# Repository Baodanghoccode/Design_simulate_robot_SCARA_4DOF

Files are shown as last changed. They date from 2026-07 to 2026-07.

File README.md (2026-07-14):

# SCARA 4-DOF Robot: Design, Simulation & Control

A full-cycle robotics project — from dynamic modeling and control design (MATLAB/Simulink), to mechanical design (SolidWorks), to a Python GUI driving a real Arduino-based prototype.

## Demo

- [Simulation & trajectory visualization](https://youtu.be/2t7z2ixyt3Y)
- [Real hardware motor control](https://youtu.be/OuQhNZBY79Q)

## Project Overview

This project covers the complete design cycle of a **4-DOF SCARA (Selective Compliance Assembly Robot Arm)**, made of 3 revolute joints and 1 prismatic (vertical) joint. The goal was to take the robot from a mathematical model all the way to a physical, motor-driven prototype:

- Derive the robot's dynamic equations of motion (mass and Coriolis matrices) from its physical parameters.
- Plan smooth joint trajectories between arbitrary start/end poses.
- Design a **computed-torque (PID) controller** and validate it in Simulink before deploying to hardware.
- Model and manufacture the mechanical structure in SolidWorks.
- Build a Python desktop application that visualizes the robot in 3D and can drive the physical arm over a serial link to Arduino.

## System Architecture

```
Trajectory Planning  →  Dynamic Control (PID)  →  Hardware (Arduino + motors)
   (MATLAB, cubic         (Simulink, mass matrix               ↓
    polynomial)            M(q) & Coriolis C(q,q̇))   Visualization (Python GUI)
```

1. **Trajectory Planning** (`matlab/traj_planning_4dof.m`) generates a smooth cubic-polynomial path for each of the 4 joints between a start and goal configuration.
2. **Dynamic Control** (`matlab/RobotScara.slx`) feeds the desired trajectory into a computed-torque control loop, using the robot's dynamic model (`matrixM.m`, `matrixC.m`) to compute the joint torques needed to track it.
3. **Hardware** — the resulting joint commands are sent over a USB-serial link to an Arduino, which drives the physical motors and reports back real joint positions.
4. **Visualization** — a Python/Tkinter GUI renders the robot in 3D in real time, using the same forward-kinematics engine whether it's driving a pure simulation or the live hardware.

## Hardware Wiring Diagram

<p align="center">
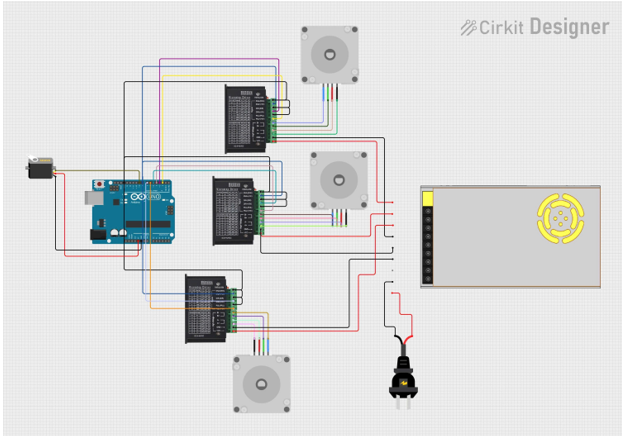
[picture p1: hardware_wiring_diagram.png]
Hardware wiring diagram: Arduino, TB6600 drivers, Nema17 motors, servo and power supply
  
</p>

Arduino Uno as the central controller, driving 3× TB6600 stepper drivers (one per stepper joint) plus a servo for the gripper, powered by a 24V switching power supply.

## Repository Structure

```
├── matlab/
│   ├── Main_Scara4dof.m          # Robot physical parameters (mass, inertia, link length) + PID gains
│   ├── traj_planning_4dof.m      # Cubic-polynomial joint trajectory generator
│   ├── matrixM.m / matrixC.m     # Mass matrix M(q) and Coriolis matrix C(q, q̇)
│   ├── tinhMa.m / tinhb.m        # Computed-torque control terms
│   ├── RobotScara.slx            # Simulink model: dynamics + PID control loop
│   ├── RobotScara.xml / RobotScara_DataFile.m
│   └── Part*.STEP                # Link geometry (STEP)
├── solidworks/                   # Native SolidWorks CAD (5 parts + assembly)
├── scara_fk_trajectory(code ve quy dao).py       # Python GUI: FK + 3D trajectory simulation (no hardware needed)
├── scara_fk_arduino (code giao dien+ketnoiarduino).py  # Python GUI: same visualization + live serial link to Arduino
└── README.md
```

## Technical Highlights

**Trajectory planning** — each of the 4 joints follows a smooth 3rd-order polynomial (zero velocity at start/end):

```
q(t) = q0 + (3/T²)(qf - q0)·t² - (2/T³)(qf - q0)·t³
```

**Dynamic control (computed torque / PID)** — uses the robot's own dynamic model to linearize and decouple the system:

```
τ = M(q)·a + C(q, q̇)·q̇ + G(q)
```

**Hardware loop** — the Arduino script streams computed joint targets over serial, reads back real position data, and renders the live 3D pose in the same GUI used for pure simulation.

## Tech Stack

`MATLAB` · `Simulink` · `SolidWorks` · `Python (Tkinter, Matplotlib, NumPy, PySerial)` · `Arduino`

## Running the Simulator

```bash
pip install numpy matplotlib pyserial
python "scara_fk_trajectory(code ve quy dao).py"              # simulation only
python "scara_fk_arduino (code giao dien+ketnoiarduino).py"   # connects to Arduino
```

## Authors

Nguyễn Tiến Bảo · Nguyễn Việt Bách

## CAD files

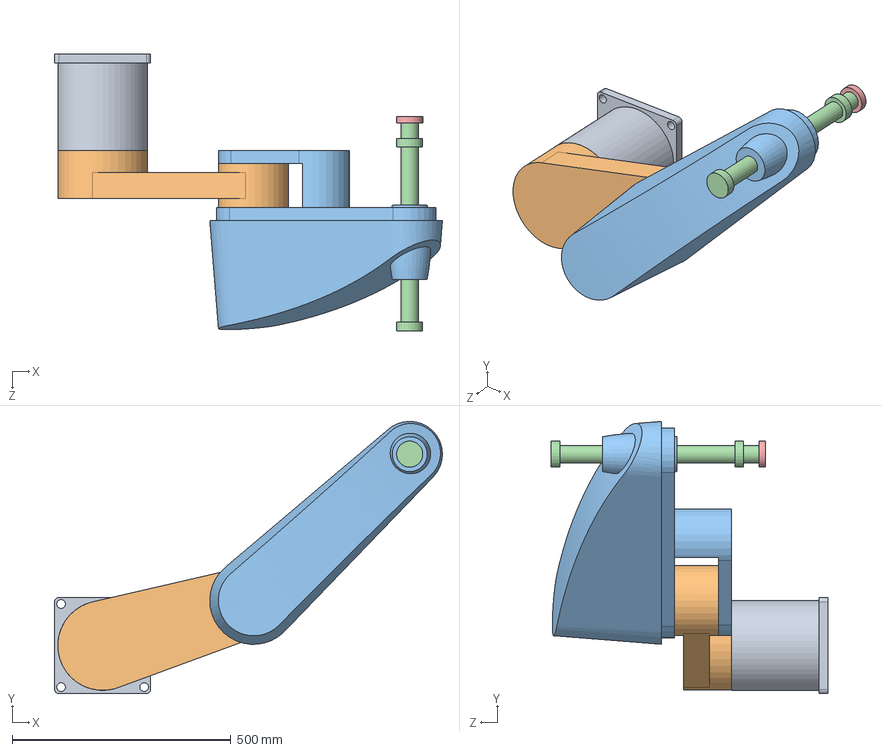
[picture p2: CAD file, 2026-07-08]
solidworks/RobotScara.SLDASM
887.5 x 622.8 x 632.5 mm

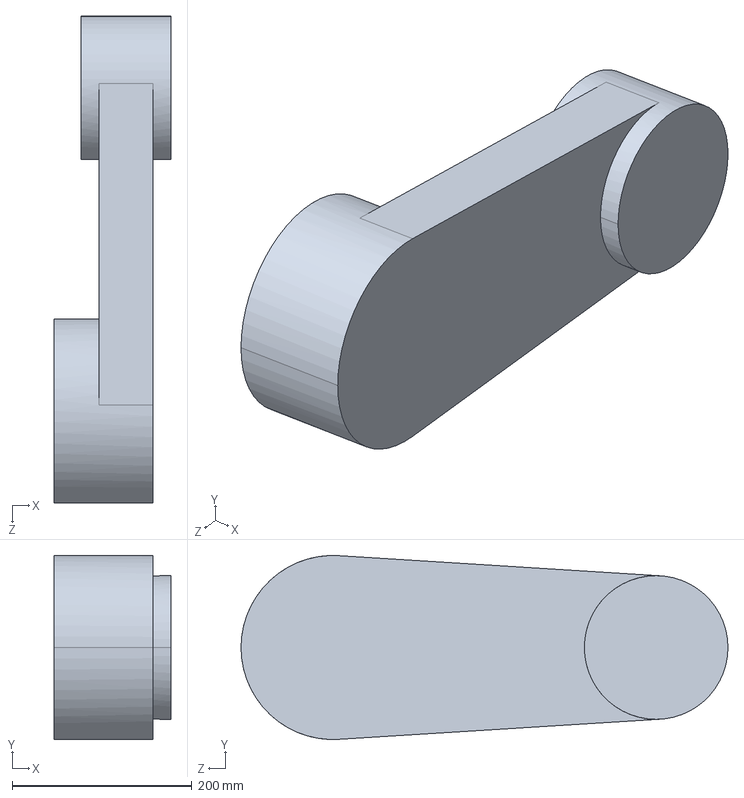
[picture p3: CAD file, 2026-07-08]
matlab/Part2_Default_sldprt.STEP
130.0 x 205.0 x 542.5 mm

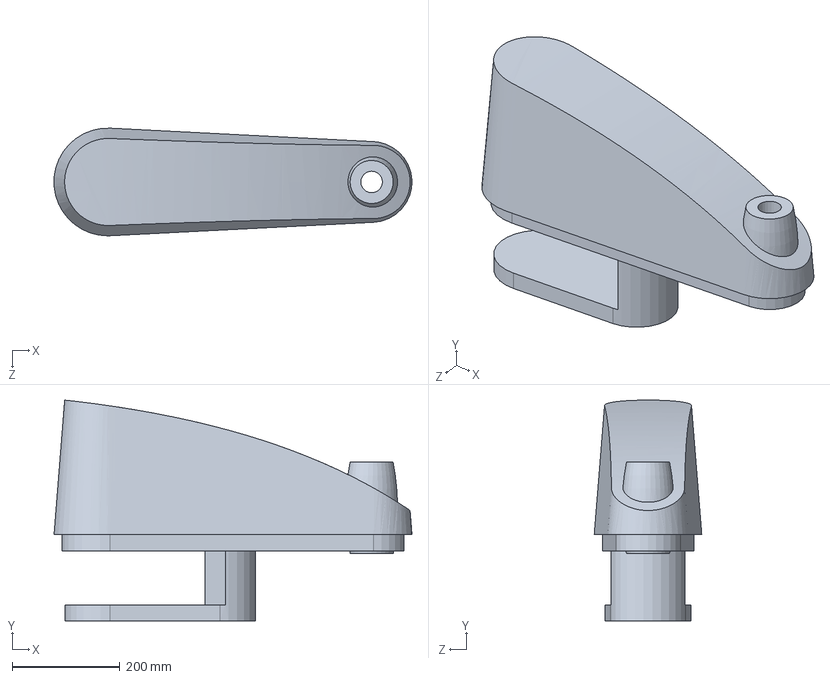
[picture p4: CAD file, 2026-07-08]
solidworks/Part3.SLDPRT
664.6 x 410.0 x 199.9 mm

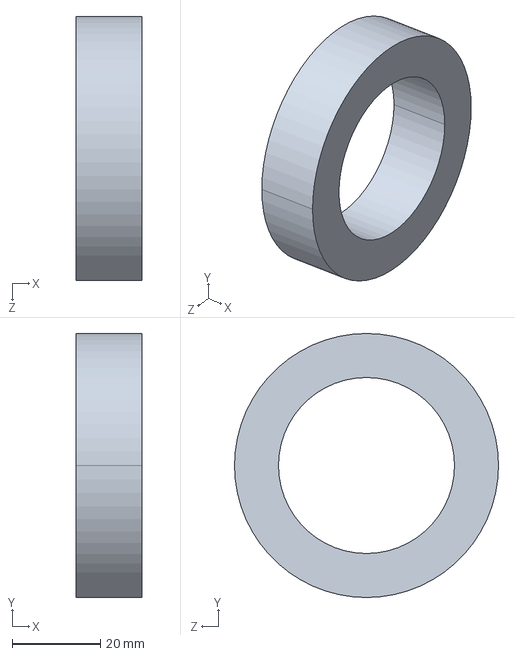
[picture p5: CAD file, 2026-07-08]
matlab/Part5_Default_sldprt.STEP
15.0 x 60.0 x 60.0 mm

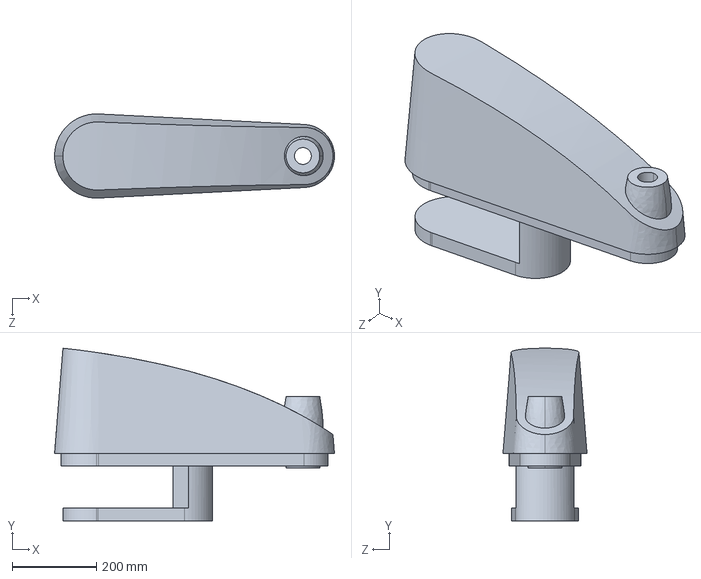
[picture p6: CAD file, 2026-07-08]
matlab/Part3_Default_sldprt.STEP
665.0 x 410.0 x 199.7 mm

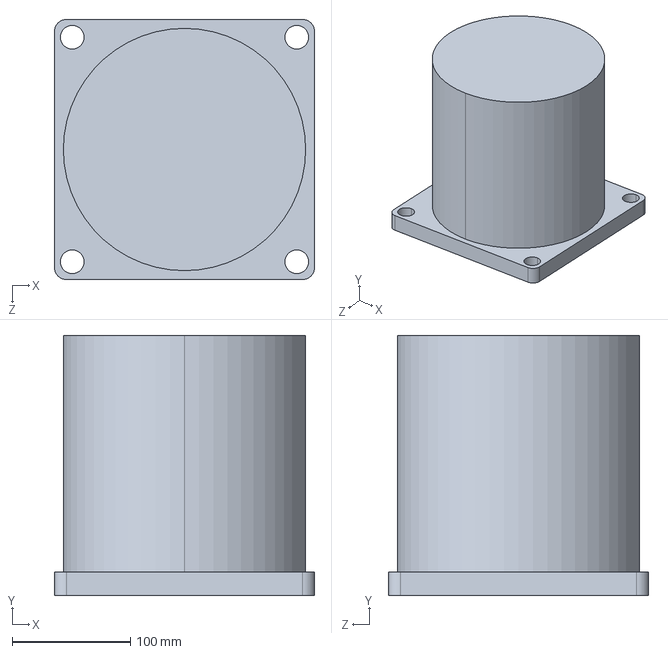
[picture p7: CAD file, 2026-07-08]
matlab/Part1_Default_sldprt.STEP
220.0 x 220.0 x 220.0 mm

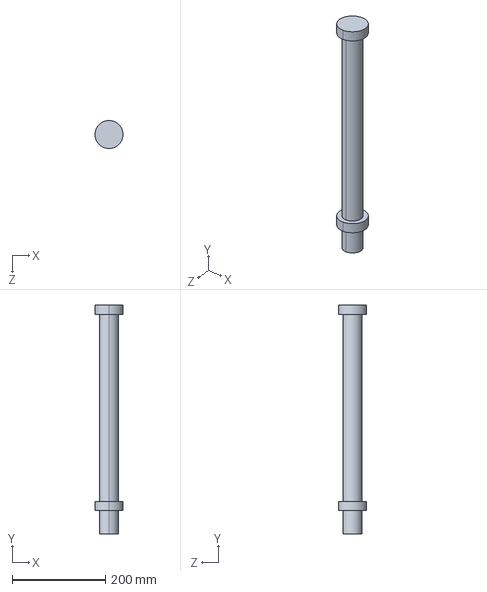
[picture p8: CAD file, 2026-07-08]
matlab/Part4_Default_sldprt.STEP
60.0 x 490.0 x 60.0 mm

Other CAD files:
solidworks/Part2.SLDPRT
solidworks/Part1.SLDPRT
solidworks/Part4.SLDPRT
solidworks/Part5.SLDPRT

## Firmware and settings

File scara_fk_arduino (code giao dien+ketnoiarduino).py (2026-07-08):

import tkinter as tk
from tkinter import font as tkfont
import numpy as np
import matplotlib
matplotlib.use("TkAgg")
from matplotlib.backends.backend_tkagg import FigureCanvasTkAgg
from matplotlib.figure import Figure
from mpl_toolkits.mplot3d import Axes3D
from mpl_toolkits.mplot3d.art3d import Poly3DCollection


import serial
import serial.tools.list_ports
import threading
import json
import queue
import time


TH = {
    "bg":       "#05070f",
    "bg2":      "#0a0d1e",
    "card":     "#0e1128",
    "card2":    "#141836",
    "input":    "#1a1e40",
    "border":   "#252b5a",
    "hi":       "#7c3aed",
    "text":     "#f0f3ff",
    "text2":    "#9aa3cc",
    "text3":    "#525d94",
    "purple":   "#a855f7",
    "blue":     "#3b82f6",
    "cyan":     "#06b6d4",
    "teal":     "#14b8a6",
    "green":    "#22c55e",
    "lime":     "#84cc16",
    "yellow":   "#eab308",
    "amber":    "#f59e0b",
    "orange":   "#f97316",
    "rose":     "#f43f5e",
    "pink":     "#ec4899",
    "j1":       "#f472b6",
    "j2":       "#a78bfa",
    "j3":       "#34d399",
    "j4":       "#fbbf24",
    "link1_a":  "#6366f1",
    "link1_b":  "#818cf8",
    "link2_a":  "#0891b2",
    "link2_b":  "#22d3ee",
    "base_c":   "#4f46e5",
    "tcp_c":    "#f43f5e",
    "grip_c":   "#f59e0b",
    "grid_c":   "#12163a",
    "floor":    "#0a0e22",
    "trough":   "#1e2354",
    
    "ped_top":  "#2a2f6e",
    "ped_side": "#1e2258",
    "ped_edge": "#4a51a8",
    "ped_ring": "#6366f1",
    "mount_c":  "#3730a3",
    "mount_hi": "#818cf8",
}


BASE_H   = 80   
BASE_R   = 55   
NECK_R   = 28   
PLATE_H  = 12   


# DH Kinematics

def dh_matrix(theta_deg, d, a, alpha_deg):
    t, al = np.radians(theta_deg), np.radians(alpha_deg)
    ct, st, ca, sa = np.cos(t), np.sin(t), np.cos(al), np.sin(al)
    return np.array([
        [ct, -st*ca,  st*sa, a*ct],
        [st,  ct*ca, -ct*sa, a*st],
        [0,   sa,     ca,    d   ],
        [0,   0,      0,     1   ]])

def forward_kinematics(t1, t2, d3, t4, l1, l2):
    T01 = dh_matrix(t1,0,l1,0)
    T12 = dh_matrix(t2,0,l2,180)
    T23 = dh_matrix(0,d3,0,0)
    T34 = dh_matrix(t4,0,0,0)
    T02=T01@T12; T03=T02@T23; T04=T03@T34
    phi = t1+t2+t4; pr = np.radians(phi)
    p = [np.zeros(3), T01[:3,3], T02[:3,3], T03[:3,3], T04[:3,3]]
    tcp = p[4]

    
    dx, dy = np.cos(pr), np.sin(pr)
    
    px, py = -np.sin(pr), np.cos(pr)

    GL = 10   
    GW = 20   
    GH = 12   

    
    lb_base = [tcp[0]+px*GW, tcp[1]+py*GW, tcp[2]]
    rb_base = [tcp[0]-px*GW, tcp[1]-py*GW, tcp[2]]

    
    lb_tip = [tcp[0]+px*GW, tcp[1]+py*GW, tcp[2]-GL]
    rb_tip = [tcp[0]-px*GW, tcp[1]-py*GW, tcp[2]-GL]

    
    grip = {
        "lb":    lb_base,
        "lt":    lb_tip,
        "rb":    rb_base,
        "rt":    rb_tip,
        
        "cross_l": lb_base,
        "cross_r": rb_base,
        
        "ar": [tcp[0]+dx*30, tcp[1]+dy*30, tcp[2]],
        
        "body_top": [tcp[0], tcp[1], tcp[2]+GH],
        "body_bot": [tcp[0], tcp[1], tcp[2]],
    }
    return {"T01":T01,"T02":T02,"T03":T03,"T04":T04,"T":T04,
            "pos":p, "x":T04[0,3],"y":T04[1,3],"z":T04[2,3],
            "phi":phi,"pr":pr,"grip":grip}

def inverse_kinematics(x, y, z, phi, l1, l2):
    r2=x**2+y**2; r=np.sqrt(r2); rm=l1+l2; rn=abs(l1-l2)
    if r>rm+1e-6: return {"error":f"Ngoài tầm với! r={r:.1f}>{rm:.1f}"}
    if r<rn-1e-6 and rn>1e-6: return {"error":f"Vùng chết! r={r:.1f}<{rn:.1f}"}
    d3=-z
    if d3<-1e-6: return {"error":f"d₃={d3:.1f}<0!"}
    c2=np.clip((r2-l1**2-l2**2)/(2*l1*l2),-1,1)
    sols={}
    for n,s in [("elbow_up",1),("elbow_down",-1)]:
        th2=s*np.arccos(c2)
        th1=np.arctan2(y,x)-np.arctan2(l2*np.sin(th2),l1+l2*np.cos(th2))
        th4=np.radians(phi)-th1-th2
        t1d=((np.degrees(th1)+180)%360)-180
        t2d=((np.degrees(th2)+180)%360)-180
        t4d=((np.degrees(th4)+180)%360)-180
        fk=forward_kinematics(t1d,t2d,d3,t4d,l1,l2)
        sols[n]={"t1":round(t1d,2),"t2":round(t2d,2),"d3":round(d3,2),"t4":round(t4d,2),"T":fk["T"]}
    return sols


def draw_cylinder_3d(ax, p1, p2, radius=12, color="#818cf8", alpha=0.85, n=12):
    """Draw a 3D cylinder between two points."""
    p1,p2 = np.array(p1),np.array(p2)
    v = p2-p1; length = np.linalg.norm(v)
    if length < 0.1: return
    v = v/length
    if abs(v[2]) < 0.99: not_v = np.array([0,0,1])
    else: not_v = np.array([1,0,0])
    n1 = np.cross(v, not_v); n1/=np.linalg.norm(n1)
    n2 = np.cross(v, n1)
    theta = np.linspace(0, 2*np.pi, n+1)
    t_line = np.array([0, 1])
    theta_grid, t_grid = np.meshgrid(theta, t_line)
    X = p1[0]+v[0]*t_grid*length + radius*(n1[0]*np.cos(theta_grid)+n2[0]*np.sin(theta_grid))
    Y = p1[1]+v[1]*t_grid*length + radius*(n1[1]*np.cos(theta_grid)+n2[1]*np.sin(theta_grid))
    Z = p1[2]+v[2]*t_grid*length + radius*(n1[2]*np.cos(theta_grid)+n2[2]*np.sin(theta_grid))
    ax.plot_surface(X, Y, Z, color=color, alpha=alpha, shade=True,
                    lightsource=matplotlib.colors.LightSource(azdeg=315,altdeg=45))

def draw_sphere_3d(ax, center, radius=15, color="#f472b6", alpha=0.9, n=10):
    """Draw a 3D sphere at a point."""
    u,v = np.meshgrid(np.linspace(0,2*np.pi,n), np.linspace(0,np.pi,n))
    X = center[0]+radius*np.cos(u)*np.sin(v)
    Y = center[1]+radius*np.sin(u)*np.sin(v)
    Z = center[2]+radius*np.cos(v)
    ax.plot_surface(X,Y,Z, color=color, alpha=alpha, shade=True)

def draw_disk_3d(ax, center, radius, normal=(0,0,1), color="#4f46e5", alpha=0.5, n=24):
    """Draw a disk (circle) at a point."""
    theta = np.linspace(0, 2*np.pi, n)
    normal = np.array(normal)/np.linalg.norm(normal)
    if abs(normal[2]) < 0.99: perp1 = np.cross(normal, [0,0,1])
    else: perp1 = np.cross(normal, [1,0,0])
    perp1 /= np.linalg.norm(perp1)
    perp2 = np.cross(normal, perp1)
    verts = []
    for t in theta:
        pt = np.array(center) + radius*(np.cos(t)*perp1 + np.sin(t)*perp2)
        verts.append(pt)
    poly = Poly3DCollection([verts], alpha=alpha, facecolor=color, edgecolor=color, linewidths=0.5)
    ax.add_collection3d(poly)


def draw_pedestal_3d(ax):
    """Draw a realistic 3-tier robot pedestal base in 3D."""
    
    draw_cylinder_3d(ax, [0,0,-BASE_H], [0,0,-BASE_H+10],
                     radius=BASE_R, color=TH["ped_side"], alpha=0.90)
    draw_disk_3d(ax, [0,0,-BASE_H], BASE_R,    color=TH["ped_top"], alpha=0.85)
    draw_disk_3d(ax, [0,0,-BASE_H+10], BASE_R, color=TH["ped_top"], alpha=0.7)
    
    t = np.linspace(0, 2*np.pi, 48)
    z0 = -BASE_H + 10
    ax.plot(BASE_R*np.cos(t), BASE_R*np.sin(t), z0,
            color=TH["ped_edge"], lw=1.2, alpha=0.7)

    
    draw_cylinder_3d(ax, [0,0,-BASE_H+10], [0,0,-PLATE_H],
                     radius=NECK_R+12, color=TH["ped_side"], alpha=0.88)
    draw_disk_3d(ax, [0,0,-PLATE_H], NECK_R+12, color=TH["ped_top"], alpha=0.65)
    
    z1, z2 = -BASE_H+10, -PLATE_H
    for angle in np.linspace(0, 2*np.pi, 7)[:-1]:
        xp = (NECK_R+12)*np.cos(angle); yp = (NECK_R+12)*np.sin(angle)
        ax.plot([xp,xp],[yp,yp],[z1,z2], color=TH["ped_edge"], lw=0.6, alpha=0.35)

    
    draw_cylinder_3d(ax, [0,0,-PLATE_H], [0,0,0],
                     radius=NECK_R, color=TH["mount_c"], alpha=0.92)
    draw_disk_3d(ax, [0,0,0],       NECK_R,   color=TH["mount_hi"], alpha=0.80)
    draw_disk_3d(ax, [0,0,-PLATE_H], NECK_R,  color=TH["ped_top"],  alpha=0.60)

    
    ring_t = np.linspace(0, 2*np.pi, 80)
    ax.plot(NECK_R*np.cos(ring_t), NECK_R*np.sin(ring_t), 0,
            color=TH["ped_ring"], lw=1.8, alpha=0.9)
    ax.plot((NECK_R+6)*np.cos(ring_t), (NECK_R+6)*np.sin(ring_t), 0,
            color=TH["ped_ring"], lw=0.5, alpha=0.3)

    
    for angle in [45, 135, 225, 315]:
        bx = (NECK_R-8)*np.cos(np.radians(angle))
        by = (NECK_R-8)*np.sin(np.radians(angle))
        draw_sphere_3d(ax, [bx, by, 1], radius=2.8, color="#94a3b8", alpha=0.9)

    
    ct = np.linspace(0, 2*np.pi, 20)
    cx, cy = (NECK_R+14)*np.cos(np.radians(270)), (NECK_R+14)*np.sin(np.radians(270))
    ax.plot([0, cx], [0, cy], [-BASE_H*0.5, -BASE_H*0.5],
            color=TH["ped_edge"], lw=2, alpha=0.25)


def draw_pedestal_side(ax, x_offset=0):
    """Draw pedestal silhouette for Side (RZ) view."""
    
    ax.fill_betweenx([-BASE_H, -BASE_H+10],
                     x_offset - BASE_R, x_offset + BASE_R,
                     color=TH["ped_side"], alpha=0.55)
    ax.plot([x_offset-BASE_R, x_offset-BASE_R], [-BASE_H, -BASE_H+10],
            color=TH["ped_edge"], lw=1.2, alpha=0.7)
    ax.plot([x_offset+BASE_R, x_offset+BASE_R], [-BASE_H, -BASE_H+10],
            color=TH["ped_edge"], lw=1.2, alpha=0.7)
    
    nw = NECK_R + 12
    ax.fill_betweenx([-BASE_H+10, -PLATE_H],
                     x_offset - nw, x_offset + nw,
                     color=TH["ped_side"], alpha=0.50)
    ax.plot([x_offset-nw, x_offset-nw], [-BASE_H+10, -PLATE_H],
            color=TH["ped_edge"], lw=1.0, alpha=0.6)
    ax.plot([x_offset+nw, x_offset+nw], [-BASE_H+10, -PLATE_H],
            color=TH["ped_edge"], lw=1.0, alpha=0.6)
    
    ax.fill_betweenx([-PLATE_H, 0],
                     x_offset - NECK_R, x_offset + NECK_R,
                     color=TH["mount_c"], alpha=0.60)
    ax.plot([x_offset-NECK_R, x_offset-NECK_R], [-PLATE_H, 0],
            color=TH["mount_hi"], lw=1.2, alpha=0.55)
    ax.plot([x_offset+NECK_R, x_offset+NECK_R], [-PLATE_H, 0],
            color=TH["mount_hi"], lw=1.2, alpha=0.55)
    
    ax.plot([x_offset-NECK_R, x_offset+NECK_R], [0, 0],
            color=TH["ped_ring"], lw=2.0, alpha=0.85)
    
    ax.plot([x_offset-BASE_R, x_offset+BASE_R], [-BASE_H, -BASE_H],
            color="#000000", lw=3, alpha=0.4)


def draw_pedestal_top(ax):
    """Draw pedestal rings for Top (XY) view."""
    tw = np.linspace(0, 2*np.pi, 80)
    
    ax.fill_between(BASE_R*np.cos(tw), BASE_R*np.sin(tw),
                    alpha=0.12, color=TH["ped_side"])
    ax.plot(BASE_R*np.cos(tw), BASE_R*np.sin(tw),
            color=TH["ped_edge"], lw=1.5, alpha=0.55, ls='--')
    
    ax.fill_between(NECK_R*np.cos(tw), NECK_R*np.sin(tw),
                    alpha=0.25, color=TH["mount_c"])
    ax.plot(NECK_R*np.cos(tw), NECK_R*np.sin(tw),
            color=TH["ped_ring"], lw=2.0, alpha=0.85)
    
    for angle in [45, 135, 225, 315]:
        bx = (NECK_R-8)*np.cos(np.radians(angle))
        by = (NECK_R-8)*np.sin(np.radians(angle))
        ax.scatter(bx, by, color="#94a3b8", s=18, zorder=6, edgecolors=TH["ped_edge"], linewidths=0.8)



class SerialManager:
    """Quản lý kết nối Serial với Arduino trong thread riêng."""
    def __init__(self):
        self.ser        = None
        self.connected  = False
        self.rx_queue   = queue.Queue()
        self._thread    = None

    @staticmethod
    def list_ports():
        return [p.device for p in sorted(serial.tools.list_ports.comports())]

    def connect(self, port, baud=115200):
        try:
            self.ser = serial.Serial(port, baud, timeout=1)
            time.sleep(2)
            self.connected = True
            self._thread = threading.Thread(target=self._read_loop, daemon=True)
            self._thread.start()
            return True, "OK"
        except Exception as e:
            return False, str(e)

    def disconnect(self):
        self.connected = False
        if self.ser and self.ser.is_open:
            self.ser.close()
        self.ser = None

    def send(self, t1, t2, d3, t4):
        if not self.connected or not self.ser:
            return False, "Chưa kết nối"
        cmd = json.dumps({"t1": round(t1,2), "t2": round(t2,2),
                          "d3": round(d3,2), "t4": round(t4,2)}) + "\n"
        try:
            self.ser.write(cmd.encode())
            return True, "Sent"
        except Exception as e:
            self.connected = False
            return False, str(e)

    def _read_loop(self):
        while self.connected and self.ser and self.ser.is_open:
            try:
                line = self.ser.readline().decode(errors='replace').strip()
                if line:
                    self.rx_queue.put(line)
            except Exception:
                break
        self.connected = False



class App:
    def __init__(self, root):
        self.root = root
        self.root.title("SCARA 4-DOF — Động Học Thuận & Nghịch  |  v4.0")
        self.root.configure(bg=TH["bg"])
        self.root.state("zoomed")
        self.root.minsize(1300,720)
        self._lock=False

        self.F = {
            "title":  tkfont.Font(family="Segoe UI",size=13,weight="bold"),
            "h2":     tkfont.Font(family="Segoe UI",size=10,weight="bold"),
            "body":   tkfont.Font(family="Segoe UI",size=9),
            "mono":   tkfont.Font(family="Consolas",size=9),
            "monob":  tkfont.Font(family="Consolas",size=10,weight="bold"),
            "monos":  tkfont.Font(family="Consolas",size=8),
            "badge":  tkfont.Font(family="Segoe UI",size=8,weight="bold"),
            "btn":    tkfont.Font(family="Consolas",size=10,weight="bold"),
            "mat":    tkfont.Font(family="Consolas",size=9),
            "mlab":   tkfont.Font(family="Segoe UI",size=7,weight="bold"),
            "tiny":   tkfont.Font(family="Consolas",size=7),
        }
        
        self.t1=tk.DoubleVar(value=30); self.t2=tk.DoubleVar(value=-45)
        self.d3=tk.DoubleVar(value=50); self.t4=tk.DoubleVar(value=0)
        self.l1=tk.DoubleVar(value=250); self.l2=tk.DoubleVar(value=200)
        self.ik_x=tk.DoubleVar(value=0); self.ik_y=tk.DoubleVar(value=0)
        self.ik_z=tk.DoubleVar(value=0); self.ik_phi=tk.DoubleVar(value=0)
        self.ik_cfg=tk.StringVar(value="elbow_up"); self.ik_sols={}
        self.view=tk.StringVar(value="3d")
        self.grid_on=tk.BooleanVar(value=True)
        self.trace_on=tk.BooleanVar(value=False)
        self.trace_pts=[]; self.animating=False

        # Serial
        self.serial_mgr  = SerialManager()
        self.auto_send   = tk.BooleanVar(value=False)
        self._last_send  = 0.0

        self._build()
        for v in [self.t1,self.t2,self.d3,self.t4,self.l1,self.l2]:
            v.trace_add("write", lambda *_: self._sched())
        self._sched()

    def _sched(self):
        if not self._lock:
            self._lock=True
            self.root.after(30, self._do_update)

    def _do_update(self):
        self._lock=False
        try:
            fk = forward_kinematics(self.t1.get(),self.t2.get(),self.d3.get(),
                                     self.t4.get(),self.l1.get(),self.l2.get())
        except: return
        for k,v in [("X",fk['x']),("Y",fk['y']),("Z",fk['z']),("φ",fk['phi'])]:
            self.res_l[k].config(text=f"{v:.2f}")
        t1,t2,t4=self.t1.get(),self.t2.get(),self.t4.get()
        d3v,l1v,l2v=self.d3.get(),self.l1.get(),self.l2.get()
        dh=[[f"{t1:.1f}","0",f"{l1v:.0f}","0"],
            [f"{t2:.1f}","180",f"{l2v:.0f}","0"],
            ["0","0","0",f"{d3v:.1f}"],
            [f"{t4:.1f}","0","0","0"]]
        for i in range(4):
            for j in range(4):
                self.dh_c[(i,j+1)].config(text=dh[i][j])
        T=fk["T"]
        for i in range(4):
            for j in range(4):
                v=T[i,j]
                self.mat_c[(i,j)].config(text=f"{v: .4f}",
                    fg=TH["cyan"] if abs(v)>0.001 else TH["text3"])
        wm=l1v+l2v; wn=abs(l1v-l2v); cur=np.sqrt(fk['x']**2+fk['y']**2)
        self.ws_l["max"].config(text=f"{wm:.0f}")
        self.ws_l["min"].config(text=f"{wn:.0f}")
        self.ws_l["cur"].config(text=f"{cur:.1f}")
        
        if hasattr(self, '_sb_items'):
            self._sb_items["tcp_xyz"].config(
                text=f"TCP: ({fk['x']:.0f}, {fk['y']:.0f}, {fk['z']:.0f}) mm")
            self._sb_items["reach"].config(
                text=f"Reach: {cur:.0f} / {wm:.0f} mm  [{cur/wm*100:.0f}%]")
        if self.trace_on.get():
            self.trace_pts.append((fk['x'],fk['y'],fk['z']))
            if len(self.trace_pts)>2000: self.trace_pts=self.trace_pts[-1500:]
        self._render(fk)
        
        if self.auto_send.get():
            now = time.time()
            if now - self._last_send >= 0.08:
                self._last_send = now
                self.serial_mgr.send(
                    self.t1.get(), self.t2.get(),
                    self.d3.get(), self.t4.get())

    
    def _build(self):
        
        hd = tk.Frame(self.root, bg=TH["bg2"], height=56)
        hd.pack(fill="x"); hd.pack_propagate(False)

        
        tk.Frame(hd, bg=TH["hi"], width=4).pack(side="left", fill="y")

        lf = tk.Frame(hd, bg=TH["bg2"]); lf.pack(side="left", padx=14, fill="y")
       
        ic = tk.Frame(lf, bg="#1e1b4b", highlightthickness=1,
                      highlightbackground=TH["purple"])
        ic.pack(side="left", padx=(0,12), pady=8)
        tk.Label(ic, text=" ⬡ ", font=("Segoe UI", 16),
                 bg="#1e1b4b", fg=TH["purple"]).pack(padx=4, pady=2)

        ttf = tk.Frame(lf, bg=TH["bg2"]); ttf.pack(side="left", fill="y", pady=6)
        tk.Label(ttf, text="SCARA Robot Controller",
                 font=tkfont.Font(family="Segoe UI", size=14, weight="bold"),
                 bg=TH["bg2"], fg=TH["text"]).pack(anchor="w")
        sub_f = tk.Frame(ttf, bg=TH["bg2"]); sub_f.pack(anchor="w")
        tk.Label(sub_f, text="Forward & Inverse Kinematics",
                 font=self.F["body"], bg=TH["bg2"], fg=TH["text3"]).pack(side="left")
        tk.Label(sub_f, text=" · ", font=self.F["body"],
                 bg=TH["bg2"], fg=TH["border"]).pack(side="left")
        tk.Label(sub_f, text="4 DOF",
                 font=tkfont.Font(family="Consolas", size=9, weight="bold"),
                 bg=TH["bg2"], fg=TH["cyan"]).pack(side="left")
        tk.Label(sub_f, text=" · Base + 3 Links + Gripper",
                 font=self.F["body"], bg=TH["bg2"], fg=TH["text3"]).pack(side="left")

        rf = tk.Frame(hd, bg=TH["bg2"]); rf.pack(side="right", padx=14, fill="y")

        def _mk_hbtn(parent, text, fg, cmd):
            f = tk.Frame(parent, bg=TH["card2"], highlightthickness=1,
                         highlightbackground=TH["border"])
            f.pack(side="right", padx=4, pady=10)
            b = tk.Button(f, text=text, font=self.F["badge"],
                bg=TH["card2"], fg=fg, bd=0, padx=16, pady=5,
                cursor="hand2", command=cmd, activebackground=TH["input"],
                activeforeground=fg)
            b.pack()
            return b

        self.btn_an = _mk_hbtn(rf, "▶  Demo", TH["cyan"], self._toggle_anim)
        _mk_hbtn(rf, "↺  Reset", TH["rose"], self._reset)

        main = tk.Frame(self.root, bg=TH["bg"])
        main.pack(fill="both", expand=True, padx=8, pady=(4,0))
        main.columnconfigure(0, weight=0, minsize=330)
        main.columnconfigure(1, weight=1)
        main.columnconfigure(2, weight=0, minsize=350)
        main.rowconfigure(0, weight=1)
        self._build_left(main)
        self._build_center(main)
        self._build_right(main)
        self._build_serial_bar()

        
        sb = tk.Frame(self.root, bg=TH["bg2"], height=24)
        sb.pack(fill="x"); sb.pack_propagate(False)
        tk.Frame(sb, bg=TH["hi"], width=4).pack(side="left", fill="y")
        self._sb_items = {}
        for key, label, col in [
            ("tcp_xyz", "TCP: —", TH["text3"]),
            ("base_h",  f"Base H: {BASE_H} mm", TH["teal"]),
            ("reach",   "Reach: —", TH["cyan"]),
            ("mode",    "Mode: FK", TH["purple"]),
        ]:
            lbl = tk.Label(sb, text=label, font=self.F["tiny"],
                           bg=TH["bg2"], fg=col)
            lbl.pack(side="left", padx=12)
            self._sb_items[key] = lbl
        tk.Label(sb, text="SCARA 4-DOF v4.0", font=self.F["tiny"],
                 bg=TH["bg2"], fg=TH["text3"]).pack(side="right", padx=12)

    def _build_serial_bar(self):
        """Thanh điều khiển Serial ở dưới cùng cửa sổ."""
        bar = tk.Frame(self.root, bg=TH["bg2"], height=44)
        bar.pack(fill="x", side="bottom")
        bar.pack_propagate(False)
        tk.Frame(bar, bg=TH["hi"], width=4).pack(side="left", fill="y")

        inner = tk.Frame(bar, bg=TH["bg2"])
        inner.pack(side="left", fill="both", expand=True, padx=8, pady=5)

        
        tk.Label(inner, text="🤖 ARDUINO", font=self.F["badge"],
                 bg=TH["bg2"], fg=TH["purple"]).pack(side="left", padx=(0,8))

        
        tk.Label(inner, text="COM:", font=self.F["badge"],
                 bg=TH["bg2"], fg=TH["text3"]).pack(side="left")

        self._com_var = tk.StringVar()
        ports = SerialManager.list_ports()
        self._com_cb = tk.OptionMenu(inner, self._com_var,
                                     *(ports if ports else ["—"]))
        self._com_cb.config(font=self.F["tiny"], bg=TH["input"], fg=TH["text"],
                            bd=0, highlightthickness=0, activebackground=TH["card2"],
                            activeforeground=TH["text"], padx=4)
        self._com_cb["menu"].config(bg=TH["card2"], fg=TH["text"],
                                    font=self.F["tiny"])
        if ports:
            self._com_var.set(ports[0])
        self._com_cb.pack(side="left", padx=(2,4))

        def _btn(txt, fg, cmd):
            return tk.Button(inner, text=txt, font=self.F["badge"],
                             bg=TH["card2"], fg=fg, bd=0, padx=10, pady=3,
                             cursor="hand2", command=cmd,
                             activebackground=TH["input"],
                             activeforeground=fg)

        _btn("⟳", TH["cyan"], self._serial_refresh_ports).pack(side="left", padx=2)
        self._btn_conn = _btn("⏻ Kết nối", TH["green"], self._serial_toggle)
        self._btn_conn.pack(side="left", padx=4)

        # ─ Gửi tay ─
        _btn("▶ Gửi", TH["cyan"], self._serial_send_now).pack(side="left", padx=2)
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

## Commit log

2026-07-14 Update README with hardware diagram and simulator setup
    Added hardware wiring diagram and instructions for running the simulator.
2026-07-14 Fix image path and author formatting in README
    Updated image source path for hardware wiring diagram and fixed author line formatting.
2026-07-14 Update number of TB6600 drivers in README
